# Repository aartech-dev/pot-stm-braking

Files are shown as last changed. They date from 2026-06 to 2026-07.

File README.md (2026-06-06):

# AART Slot Car Braking Module

## TODO

    - Verify the design  
    - Get AI to produce KiCad files - again and retrofit the pretty libs etc.

**AART — Adrian & Richard's Technologies**

An [open source](https://creativecommons.org/licenses/by-nc-sa/4.0/) standalone electronic braking controller for slot car racing, supporting brushed and brushless motors. Connects between the hand controller and the track via standard 4mm banana plugs. Compatible with any conventional resistor or transistor hand controller.

> *With thanks to Bob Budge for the original concept.*

---

## What it does

When a driver releases the trigger, a conventional hand controller shorts the track terminals. The motor becomes a generator and this module controls how that energy is absorbed — from a gentle soft brake through to a dead short, with optional positive anti-brake injection and brushless eCom keep-alive.

Three operating modes cover the main competition use cases:

| Mode | Toggle position | Use case |
|---|---|---|
| **A — Positive anti-brake** | A | Brushed motors (high-Kv, Group 12) where hard braking causes deslotting. Pot: CCW = soft brake → centre = dead short → CW = forward voltage injection (0–2V) |
| **B — Reduced braking** | B | Brushed motors needing fine brake adjustment. Full pot range: CCW = ~8Ω → CW = dead short |
| **C — Brushless keep-alive** | C | Brushless motors with eCom. Brake resistance same as mode B, plus a continuously-present low voltage keeps the eCom MCU powered at all times |

**Brake detection** is by voltage sense on the track positive (BLACK) terminal — no mechanical wiper strip contact required. Compatible with any hand controller.

**Brake ramp-in** (modes A and B): configurable exponential onset from 0 to 200ms, giving the "active coast" feel of advanced commercial controllers.

---

## Physical connections

Six 4mm banana sockets — three to the track, three to the hand controller:

| Colour | Signal | Notes |
|---|---|---|
| WHITE | +12–16V always-live rail | From track PSU (40–90A capable). Powers the module. |
| BLACK | Track positive | To car via right-hand braid. Monitored for brake detection. |
| RED | Common negative | Left-hand braid return. |

The module mirrors these three sockets on its output side for the hand controller to plug into.

---

## Repository layout

```
pot-stm-braking/
├── aart-brake-ocm3-fixed/      # Firmware (libopencm3, Docker toolchain)
│   ├── Dockerfile
│   ├── docker-compose.yml
│   ├── firmware/
│   │   ├── Core/
│   │   │   ├── Inc/brake_module.h   # Constants, pin map, types, API
│   │   │   └── Src/
│   │   │       ├── brake_module.c   # Control logic, ADC/DMA, PWM, flash
│   │   │       └── main.c           # SysTick ISR, fault handlers, main loop
│   │   ├── Makefile
│   │   └── stm32g041j6.ld           # Custom linker script (page 31 reserved)
│   └── scripts/
│       ├── build.sh
│       ├── flash.sh
│       └── debug.sh
├── aart-brake-kicad/               # KiCad schematic and BOM
│   ├── aart_brake.kicad_pro
│   ├── aart_brake.kicad_sch
│   └── aart_brake_bom.csv
├── scripts/                        # Document generator
│   └── gen_doc.js
├── AART_Braking_Module_Design_v8.docx   # Full design document
└── README.md
```

---

## Hardware

**MCU:** STM32G041K6U6 (QFN-32, Cortex-M0+, 32K flash, 8K RAM, 64MHz)

**Key pin assignments:**

| Pin | Signal | Function |
|-----|---|---|
| PA0 | WHITE sense | ADC — 16V rail ÷ 18k/4k7 divider → 3.31V max |
| PA1 | BLACK sense | ADC — track voltage ÷ 22k/4k7 divider → 2.82V max. Brake detection. |
| PA2 | Toggle bit 0 | GPIO pull-up — mode select |
| PA3 | Pot wiper | ADC — 10k centre-detent pot |
| PA4 | Toggle bit 1 | GPIO pull-up — mode select |
| PA5 | Capture button | ADC — 10k pull-up + 1k series. ~4095 unpressed, ~372 pressed |
| PA6 | TIM3_CH1 | Brake PWM → GD1 → Q1 (N-ch, **inverted polarity**) |
| PA7 | TIM3_CH2 | Keep-alive PWM → GD2 → Q2 (P-ch, normal polarity) |
| PB6 | Status LED | Blinks 3× on flash save |

**Power components (revised after thermal analysis):**

| Ref | Part | Notes |
|-----|---|---|
| Q1 | IRLB3034 N-ch D2PAK | Brake FET, 195A/40V, 1.4mΩ Rds(on) |
| Q2 | IRF9Z34N P-ch D2PAK | Keep-alive/anti-brake FET, 18A/55V |
| D1 | **P6KE18CA** (bidirectional) | TVS rail clamp — CA suffix required for both polarities |
| D2/D3 | **SS310** (3A/100V) | FET catch diodes — 100V rating required on 16V rail |
| D4 | **MBRS360 or SS54** | Mode C series protection — most stressed diode, sees repetitive ~46A pulses at 20kHz |
| F1 | 500mA–1A polyfuse | **WHITE rail MCU supply only** — never in the BLACK track path |
| U2 | AMS1117-3.3 SOT-223 | LDO, 12–16V → 3.3V |

> **D4 is essential in mode C.** Without it, Q2's body diode takes the full braking energy pulse every time Q1 fires. See design document section 3.5 for the full thermal analysis.

---

## Firmware

Built with [libopencm3](https://github.com/libopencm3/libopencm3) — no ST HAL, no CubeMX, no proprietary dependencies.

**ADC scan (4 channels, DMA circular):** WHITE rail → BLACK track → pot → capture button

**PWM:** TIM3 at 20kHz. CH1 uses **inverted polarity** (CCR=0 → pin HIGH → Q1 on → dead short). This means the 10kΩ pull-up on GD1's input holds the brake on when the MCU is unpowered — the safe failure mode.

**Brake ramp-in** uses an exponential geometric decay:
```
ccr += (target − ccr) × alpha / 256   (each 1ms tick)
```
`alpha` is derived from the saved ramp time: 0ms = immediate, 200ms = slowest. The shape gives fast initial brake onset (prevents running wide) with a gentler tail (avoids snap-stop).

**Flash storage (page 31, address 0x08007C00):**
```
[63:48] ramp_ms    (0–200ms)
[47:32] ka_ccr     (0–400, keep-alive CCR)
[31:0]  magic      (0xAA270001)
```

---

## Building

### Prerequisites

- Docker Desktop (Apple Silicon Mac — linux/arm64)
- Git

### Build the Docker image

```bash
cd aart-brake-ocm3-fixed
docker build --target toolchain -t aart-brake:toolchain .
```

First build: ~5 minutes (ARM GCC 13.3 download + libopencm3 G0 compile). Subsequent builds are cached and near-instant.

### Compile

```bash
# Debug build
docker compose run --rm brake build

# Release build
docker compose run --rm brake build release
```

Output lands in `./build/` on the host:

| File | Description |
|---|---|
| `aart_brake.elf` | Debug ELF with symbols (GDB) |
| `aart_brake.hex` | Intel HEX |
| `aart_brake.bin` | Raw binary |
| `aart_brake.map` | Linker map |

Typical size: ~5–6KB text, well within 32K flash.

### Flash (recommended: build in Docker, flash from host)

Docker Desktop on macOS does not reliably pass USB devices to containers.

```bash
# ST-Link
brew install stlink
st-flash write build/aart_brake.bin 0x08000000

# Or via OpenOCD
brew install openocd
openocd -f interface/stlink.cfg -f target/stm32g0x.cfg \
    -c "program build/aart_brake.elf verify reset exit"
```

### Debug (GDB via OpenOCD)

```bash
docker run --rm --privileged -it \
    -v "$(pwd)/build:/workspace/build" \
    -v "$(pwd)/firmware:/workspace/firmware" \
    -p 3333:3333 \
    aart-brake:toolchain \
    /workspace/scripts/debug.sh stlink
```

GDB connects automatically and breaks at `main()`.

---

## Capture procedure

### Keep-alive voltage (mode C — brushless)

1. Set toggle to **C**
2. Hold capture button — brake is suspended, pot dials Q2 output 0→2V
3. Rotate pot CW slowly until eCom powers up (LED or other indicator)
4. Continue slowly until motor just begins to twitch, then back off slightly
5. Release button — voltage saved to flash, LED blinks 3×
6. Power cycle to verify: eCom should power on immediately

### Brake ramp time (modes A and B)

1. Set toggle to **A** or **B**
2. Hold capture button — pot dials ramp time CCW=0ms → CW=200ms
3. Release button — ramp time saved to flash, LED blinks 3×

Starting points: wing cars 80–150ms, pan cars 0–30ms.

---

## libopencm3 G0-specific notes

The STM32G0 has several differences from F-series that affect libopencm3 usage:

- **DMAMUX** — G0 DMA uses a DMAMUX peripheral. ADC1→DMA1 CH1 requires writing `MMIO32(0x40020800) = 5` (not available via the library on all versions)
- **ADC scan** — `adc_enable_scan_mode()` does not exist on G0; scan is implicit when sequence length > 1
- **ADC symbols** — `ADC_CFGR1_RES_12_BIT` not `ADC_RESOLUTION_12BIT`; `ADC_SMPR_SMPx_039DOT5CYC` not `ADC_SMPR_SMP_39DOT5CYC`
- **Timer reset** — use `rcc_periph_reset_pulse(RST_TIM3)` not `timer_reset()`
- **Linker script** — libopencm3 dropped per-device `.ld` files; `stm32g041j6.ld` is provided in the repo with `MEMORY{}` + `INCLUDE cortex-m-generic.ld`
- **Flash writes** — G0 flash requires 64-bit aligned double-word writes

---

## BSCRA / ISRA legality

Anti-brake and keep-alive voltages are sourced directly from the WHITE (track PSU) rail. No stored energy — no capacitors, batteries, or supercapacitors. This satisfies the direct track power requirement in current BSCRA and ISRA controller regulations. Verify against specific class rules for your event.

---

## Design document

`AART_Braking_Module_Design_v8.docx` covers:

- Physical connections and signal chain
- Three-mode operation with FET truth tables
- Hardware component list with power/thermal analysis
- Pin assignments and voltage divider calculations
- Peripheral configuration (clock, TIM3, ADC, DMA, flash)
- Key design decisions with rationale
- libopencm3 build notes and G0-specific API differences
- Docker toolchain setup
- Pre-commissioning checklist and scope verification sequences
- On-track tuning guidance
- Industry terminology (positive anti-brake vs reduced braking)
- Brake ramp-in theory and setup recommendations
- Power and thermal analysis for all power-carrying components

---

## Toolchain

| Tool | Version |
|---|---|
| arm-none-eabi-gcc | 13.3.rel1 (ARM official, arm64 native) |
| OpenOCD | 0.12.0 (via Debian Bookworm apt) |
| libopencm3 | master (cloned and built in Docker image) |
| Base OS | Debian Bookworm slim |

---

## Acknowledgements

- Bob Budge — original concept
- Arseny Vakrushev — ESCape32 firmware (related AART work)
- Keith Gibson — brake module contributions
- libopencm3 contributors

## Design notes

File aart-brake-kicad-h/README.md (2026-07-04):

# AART Brake Module — KiCad Schematic (hierarchical, Revision 11)

Firmware Rev 11 design. Open `aart_brake.kicad_pro` in **KiCad 7.0+**.
The schematic is hierarchical: the root sheet (`aart_brake.kicad_sch`)
contains seven sub-sheet symbols. These are annotation-style sheets
(net labels + text callouts; no placed library symbols), so they open
without missing-symbol warnings and document the design for layout.

## Sheets
| # | File | Contents |
|---|---|---|
| root | `aart_brake.kicad_sch` | Top level, component list, design notes |
| 1 | `power_supply.kicad_sch` | F1, D1 TVS, U2 +3V3 LDO, **U4 +5V analog LDO** (powers INA210/LM311 ideal diode; gate-drive charge pump from WHITE) |
| 2 | `mcu_inputs.kicad_sch` | U1 STM32G051, **DAC1 PA4 brake, DAC2 PA5 anti-brake**, pot, toggle PB0/PB1, sense |
| 3 | `debug_headers.kicad_sch` | SWD, UART, BOOT0, NRST |
| 4 | `brake_fet.kicad_sch` | **Q2 TW100N03CC** low-Rds logic-level, **GD2 op-amp buffer**, linear (no PWM) |
| 5 | `keepalive_fet.kicad_sch` | **Anti-brake constant-current source: GD1 + Q1 TIP147 + Rsense 0.1ohm, DAC2-set 3A** |
| 6 | `track_connectors.kicad_sch` | J1-J6 banana; BLACK split by the reverse switch |
| 7 | `reverse_switch.kicad_sch` | **Q5/Q6 N-ch pair + U5 INA210 + U6 LM311 ideal diode (~2us, ~0.16A trip)** |

## Latest design changes (Revision 11)
- **Reverse-block driver is now an INA210 + LM311 ideal diode**, replacing the TPS1212-Q1.
  An INA210 current-sense amp (gain 200, +5V) across Rsns_sw (~1mohm) feeds an LM311 comparator
  (~50mV hysteresis, ~0.16A trip) that turns the Q5/Q6 pair off on reverse current in ~2us (sim) -
  ~13x lower glitch energy than the TPS1212, so a smaller eCom brownout when the brake contact closes.
  This drops the TPS1212 I2t/SCP/IMON automotive protection (open item: the brake event is brief and
  the rest of the design is unprotected, but the pass FETs lose their own fault protection). OPEN ITEMS:
  a high-side gate driver / charge pump (from WHITE) must lift the gates above the 0-16V BLACK common
  source; the ~2us speed and the 26V INA210 CM ceiling need bench validation.
- **Anti-brake is now a constant-current source** (3A), not a voltage follower. GD1 op-amp +
  Q1 TIP147 PNP Darlington + 0.1ohm sense; demand is DC from DAC2 (R_KA1/R_KA2 divider + GD3 LM7321 translator).
  Bounds the current at stall (a near-short on the start line) and matches real controllers.
  Anti-brake net is KA_DAC_DEMAND; PA5 = DAC2 (DAC_CH2) direct DC demand.

## What changed across earlier schematic revisions (now unified as Revision 11)
This schematic was two design generations behind. Updated to match the
current design document (v29) and firmware Rev 11:

- **DAC, not PWM.** PA4/PA5 dual DAC drive op-amp buffers in linear mode.
  TIM3 PWM gate drive retired. (PB4 now drives the TM1637 digital display; the PB4 voltmeter PWM is retired.)
- **Op-amp buffers, not UCC27524** for both gate channels.
- **Anti-brake = constant-current source** (Q1 TIP147 + GD1 HV op-amp + Rsense
  0.1ohm), superseding the earlier TIP122 voltage follower. DAC2 sets the current
  demand via R_KA1/R_KA2 + GD3 LM7321: code 0 = off, full = 3A (DAC_KA_OFF is now 0).
  Retired: IRF9Z34N, ZD1/R_Z1/C_Z1, LM321 floating supply; TIP122 follower.
- **Brake FET → Q2 TW100N03CC** (low-Rds logic-level, full-on for brushless;
  IRFP250N = brushed-only alt). Q1 (TIP147) runs linear ~10-15W and **requires a heatsink**.
- **Reverse-block pass element (sheet 7):** two N-channel (Q5/Q6, common-source)
  + U5 INA210 + U6 LM311 ideal-diode controller (ICs on +5V), with Rsns_sw (~1mohm)
  sense, ~0.16A reverse trip, ~50mV hysteresis, ~2us. No I2t/SCP/IMON; gate-drive charge
  pump from WHITE (open item). Supersedes the TPS1212-Q1. ~87mV at 40A.
- **Toggle PB0/PB1**, capture button removed, **PB3 free** (the ideal diode
  has no enable input; the TPS1212 EN is gone).
- **+5V analog rail (U4)** for the GD2 brake gate buffer (GD1 runs on WHITE).

## Net names
| Net | Description |
|---|---|
| `+12V_RAIL` | WHITE, always-live 12-16V from track PSU |
| `+3V3` | MCU rail (U2) |
| `+5V` | Analog rail (U4): GD2 brake gate buffer |
| `GND` | Common ground (RED rail / 0V) |
| `CTRL_BLACK_IN` | Controller BLACK in (J4) → reverse switch input |
| `TRACK_POS` | Track BLACK (J3); switch output; motor +; injection node |
| `DAC1_Q2_BRAKE` / `KA_DAC_DEMAND` | DAC1 brake; DAC2 anti-brake demand |
| `PB3` | Free GPIO (was reverse-switch enable; ideal diode has no enable) |

## Note on the .kicad_pro
Child sheets are referenced by the sheet symbols in the root `.kicad_sch`;
KiCad assigns page numbers/UUIDs on first open. The hierarchy will populate
automatically. These sheets are documentation-grade (labels + callouts);
place real symbols/footprints in KiCad for board layout.

Revision 11 — 19 June 2026 — AART (Adrian & Richard's Technologies)

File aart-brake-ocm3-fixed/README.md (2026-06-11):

# AART Brake Module — Docker Toolchain (libopencm3)

STM32G051K6U6 firmware built with **libopencm3** — no ST HAL,
no CubeMX, no proprietary dependencies. Everything in the repo.

---

## Why libopencm3?

- Fully open source (LGPL) — the library lives in the repo as a submodule
- No CubeMX, no ST account, no generated code blobs
- Direct register-level control with thin, readable wrappers
- Smaller binaries than HAL
- One important difference on G0: the DMA controller uses a **DMAMUX**
  which must be configured explicitly (see `dma_setup()` in brake_module.c)

---

## Project layout

```
aart-brake-ocm3/
├── Dockerfile              # base → toolchain → cubeprog (optional)
├── docker-compose.yml
├── README.md
├── .dockerignore
├── .gitignore
├── .gitmodules             # libopencm3 as submodule
├── firmware/
│   ├── Core/
│   │   ├── Inc/
│   │   │   └── brake_module.h
│   │   └── Src/
│   │       ├── main.c
│   │       └── brake_module.c
│   └── Makefile
├── scripts/
│   ├── entrypoint.sh
│   ├── build.sh
│   ├── flash.sh
│   └── debug.sh
└── build/                  # created at build time, gitignored
```

---

## Prerequisites

- Docker Desktop for Mac (Apple Silicon)
- Git (for submodule init)
- ST-Link V2/V3 or J-Link probe

---

## First-time setup

### 1. Initialise the libopencm3 submodule

After cloning the repo:

```bash
git submodule update --init --recursive
```

This is only needed on the host if you want to browse the source.
The Docker image clones libopencm3 independently at build time
and pre-builds the G0 library — so the submodule is optional
for Docker users but useful for IDE navigation.

The `.gitmodules` entry looks like this:
```ini
[submodule "libopencm3"]
    path = libopencm3
    url = https://github.com/libopencm3/libopencm3.git
    branch = master
```

### 2. Build the Docker image

```bash
docker build --target toolchain -t aart-brake:toolchain .
```

First build: ~5 minutes (ARM GCC download + libopencm3 compile; OpenOCD from apt is fast).
Subsequent builds: seconds (all layers cached).

---

## Compile the firmware

```bash
# Debug build (default)
docker compose run --rm brake build

# Release build (optimised, no debug symbols)
docker compose run --rm brake build release
```

Or directly without compose:
```bash
docker run --rm \
    -v "$(pwd)/firmware:/workspace/firmware" \
    -v "$(pwd)/build:/workspace/build" \
    aart-brake:toolchain \
    /workspace/scripts/build.sh
```

Output in `./build/`:
| File | Description |
|---|---|
| `aart_brake.elf` | Debug ELF with symbols (for GDB) |
| `aart_brake.hex` | Intel HEX (for CubeProgrammer) |
| `aart_brake.bin` | Raw binary |
| `aart_brake.map` | Linker map |

Expected size on STM32G051K6U6 (32K flash, 18K RAM, DAC):
- Text: ~4–6 KB
- BSS: ~100 bytes
- Very comfortable margins.

---

## Flash the firmware

**Recommended on macOS: build in Docker, flash from host.**

Docker Desktop on macOS does not reliably pass USB devices
through to containers. The simplest workflow is:

```bash
# 1. Build inside Docker
docker compose run --rm brake build

# 2. Flash from host using ST-Link tools (install via Homebrew)
brew install stlink
st-flash write build/aart_brake.bin 0x08000000

# OR using openocd on the host
brew install openocd
openocd \
    -f interface/stlink.cfg \
    -f target/stm32g0x.cfg \
    -c "program build/aart_brake.elf verify reset exit"
```

**If you want to flash from inside the container:**
```bash
docker run --rm --privileged \
    -v "$(pwd)/build:/workspace/build" \
    aart-brake:toolchain \
    /workspace/scripts/flash.sh stlink
```
Note: `--privileged` is required for USB access on macOS.

---

## Debug (GDB)

```bash
# Start OpenOCD + GDB inside the container
docker run --rm --privileged -it \
    -v "$(pwd)/build:/workspace/build" \
    -v "$(pwd)/firmware:/workspace/firmware" \
    -p 3333:3333 \
    aart-brake:toolchain \
    /workspace/scripts/debug.sh stlink
```

GDB breaks at `main()` automatically. Useful commands:

```gdb
(gdb) p s_state              # print full BrakeState_t struct
(gdb) p brake_get_mode()     # current mode
(gdb) info locals            # local variables in current frame
(gdb) x/2h &s_adc_buf        # raw ADC DMA buffer (hex halfword)
(gdb) monitor reset halt     # reset MCU and halt
(gdb) continue               # run
(gdb) quit
```

---

## libopencm3 — G0-specific notes

### DMAMUX
The STM32G0 family routes DMA requests through a DMAMUX
peripheral, unlike F0/F1 where the mapping is fixed.
You must configure `DMAMUX1_CxCR` for each DMA channel.

In `brake_module.c`:
```c
// Route ADC1 (request ID 5) to DMA1 Channel 1
dmamux_set_dma_channel_request(DMAMUX1, 0, ADC_DMAMUX_REQ);
```
If you add more DMA channels, set DMAMUX accordingly.

### ADC calibration
On the G0 ADC, `adc_calibrate()` must be called **before**
`adc_power_on()`. libopencm3 handles this correctly if called
in the right order — see `adc_setup()` in brake_module.c.

### Linker script
libopencm3 ships `stm32g051k6.ld` with the correct
flash (32K) and RAM (8K) sizes for this exact part.
No need to write your own.

### ISR names
libopencm3 uses lowercase ISR names with weak defaults:
- `sys_tick_handler` — SysTick (1ms tick)
- `hard_fault_handler` — HardFault (force brake)
- `nmi_handler` — NMI (force brake)
- `dma1_channel1_isr` — DMA complete (ADC results ready)

Override them in your C files — no startup file editing needed.

---

## Optional: STM32CubeProgrammer stage

Download `SetupSTM32CubeProgrammer.linux` from ST (free myST account),
place in `./installers/`, then:

```bash
docker build --target cubeprog -t aart-brake:full .
```

Flash with CubeProgrammer:
```bash
docker run --rm --privileged \
    -v "$(pwd)/build:/workspace/build" \
    aart-brake:full \
    STM32_Programmer_CLI -c port=SWD -w /workspace/build/aart_brake.elf -v -rst
```

---

## Toolchain versions

| Tool | Version |
|---|---|
| arm-none-eabi-gcc | 13.3.rel1 |
| OpenOCD | 0.12.0 (via apt, Debian Bookworm) |
| libopencm3 | master (pinned at image build) |
| Base OS | Debian Bookworm slim |

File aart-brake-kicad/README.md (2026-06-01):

# AART Brake Module — KiCad Schematic

## Files

| File | Description |
|---|---|
| `aart_brake.kicad_pro` | KiCad project file — open this in KiCad |
| `aart_brake.kicad_sch` | Schematic — single sheet, A2 paper |
| `aart_brake_bom.csv` | Bill of materials with footprints and notes |

## Opening

Open `aart_brake.kicad_pro` in **KiCad 7.0 or later**. The schematic
uses only inline symbol definitions (no external library dependencies),
so it should open without any missing symbol warnings.

## Schematic layout

The sheet is arranged left-to-right by signal flow:

```
[Connectors/Inputs] → [MCU U1] → [Gate Drivers GD1/GD2] → [FETs Q1/Q2] → [Track Connectors]
[Power rail J2/F1/D1/U2] runs across the top
[Status LED] sits below the MCU
```

## Key design decisions (see also design document)

**Q1 (brake FET, N-ch low-side):**
TIM3_CH1 uses INVERTED output polarity. CCR=0 → pin HIGH → Q1 fully on → dead short.
The 10kΩ pull-up R2 is on the GD1 *input* (not Q1's gate). When the MCU is unpowered,
R2 holds GD1 input HIGH → Q1 stays on → motor remains shorted = safe default.

**Q2 (keep-alive FET, P-ch high-side):**
IRF9Z34N with gate driven by GD2 (UCC27524). P-channel: gate LOW = FET on.
TIM3_CH2 uses normal polarity: CCR=0 → pin LOW → Q2 off.

**D4 (mode C protection):**
SS34 Schottky in series with Q2 drain output, oriented so current flows
Q2 → D4 → track+. When Q1 hard-brakes (dead short), D4 blocks the reverse
current spike from the track back through Q2's body diode.
D4 is ESSENTIAL for mode C. It can be omitted on mode A/B-only boards.

**Gate driver note:**
The UCC27524 is a dual low-side gate driver. Both outputs (OUTA, OUTB) are
wired in parallel for each FET to double the gate drive current capability.
For Q2 (P-channel), the driver output drives the gate low to turn the FET on.
The gate drive supply for GD1/GD2 is 3.3V (from U2). Verify that 3.3V is
sufficient to fully enhance the chosen FETs (Vgs(th) must be < 3.3V).
Both IRLB3034 and IRF9Z34N are logic-level parts and work correctly at 3.3V.

## Net names

| Net | Description |
|---|---|
| `+12V_RAIL` | Always-live 12.4V from track PSU |
| `+3V3` | 3.3V from LDO U2 |
| `GND` | Common ground |
| `TRACK_POS` | Track positive output (to car) |
| `TRACK_NEG` | Track negative / GND |
| `CTRL_IN` | Hand controller output (0–12.4V) |

## Schematic version

Rev 1.0 — May 2026 — AART (Adrian & Richard's Technologies)

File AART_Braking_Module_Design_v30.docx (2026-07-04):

AART Slot Car Braking Module

Design Document

Target MCU: STM32G051K6U6 (QFN-32) | Firmware: Rev 11 | libopencm3

Revision 11 | 19 June 2026 | AART — Adrian & Richard’s Technologies

PRIVATE & CONFIDENTIAL

With gratitude to Jeff Goldberg for his manifold contributions to this work.

# 1. Overview

This document describes the hardware design and firmware architecture for the AART slot car braking module. The module connects in-line between a conventional hand controller and the track, providing variable resistance braking, positive anti-brake for brushed motors, and a keep-alive voltage floor for brushless motors. All three functions are controlled by a three-position toggle switch and a single linear potentiometer, with fine tuning via UART commands.

## 1.1 Purpose

The AART brake module provides three capabilities, controlled by a three-position toggle switch, a linear potentiometer, and UART commands:

- Braking — for brushed and brushless motors. Q2 shunts a variable resistance across the motor terminals. The pot governs brake force from a settable minimum (selectable 25/15/5/4/3/2/1Ω via SET BRAKE_OHMS, full CCW) to dead short (full CW). Fine electronic control replaces the fixed resistor of a conventional brake.
- Anti-brake — for brushed motors (Mode B). While braking, Q1 injects a small forward current from the WHITE rail that opposes the brake, countering the back-EMF that makes the car snap on corner entry. The pot simultaneously governs both brake resistance and anti-brake level through a lookup table: lighter braking gives more anti-brake, harder braking less.
- Keep-alive floor — for brushless motors (Mode A with floor set). The eCom is powered from the braid. Conventional braking collapses the braid voltage to near zero, resetting the eCom. Q1 clamps the braid above a settable floor, preventing brownout. The floor is set by rotating the pot in Mode C then toggling to Mode A.

Parameters requiring fine or infrequent adjustment — ramp-in time, trail brake release, brake entry/exit thresholds, and Latvian brake — are set via UART and saved to flash.

The module is fully compatible with any conventional hand controller and requires no modification to the controller or the car.

## 1.2 System position

The module connects via 4mm banana plugs to the three standard track sockets and exports matching sockets for the hand controller to plug into. It is fully transparent during normal running and takes over braking when the controller shorts the track.

Banana colour | Signal | Description
WHITE | +12–16V always-live rail | From track PSU. Can deliver 40–90A. Powers the module and Q1 injection.
BLACK | Track positive (+ve to car) | Controlled by hand controller. Monitored by module to detect brake condition.
RED | Common negative | Left braid return. Module and track ground reference.

The module presents identical WHITE/BLACK/RED sockets on its output side for the hand controller to plug into. During normal running, BLACK passes through unmodified. When the hand controller shorts BLACK→RED (brake condition), the module detects this by voltage sense on the BLACK terminal and applies its own controlled braking.

The WHITE rail is always live at 12–16VDC regardless of throttle position. The hand controller varies how much of this rail reaches the BLACK output. The module draws its MCU supply from WHITE via the LDO. WHITE is also the source for Q1 (anti-brake injection and keep-alive floor).

## 1.3 Circuit topology

The diagram below shows the principal signal paths through the module. All three rails (WHITE, BLACK, RED) run left to right. The hand controller connects on the left; the track and motor are on the right.

[Figure 1: Circuit topology diagram — see AART_Brake_Topology.svg delivered alongside this document]

Key points from the diagram:

- The reverse-blocking switch (two N-channel + INA210/LM311 ideal diode, section 7A.2) sits in the BLACK controller input path — not the WHITE rail. During normal running it is fully transparent (near-zero voltage drop). During brake takeover it opens, isolating the controller’s short from the track.

Note: The reverse-blocking element is a two N-channel common-source bidirectional switch controlled as an ideal diode by an INA210 current-sense amp and an LM311 comparator (both on +5V), not an anode-powered ideal-diode IC — see section 7A.2. The LM311 turns the pair off on reverse current in ~2µs (sim), with a ~0.16A trip threshold and ~50mV hysteresis. This drops the automotive I²t / 5µs short-circuit / IMON protection of the earlier TPS1212-Q1 (open item). Insertion drop ~87mV at 40A including the sense resistor.

- Q1 (TIP147 PNP Darlington) is the pass device of the anti-brake / keep-alive constant-current source: the WHITE-rail op-amp GD1 regulates the current through Q1 and Rsense (0.1Ω) to I = Vdemand/Rsense, up to ~3A. In Mode A it holds the saved keep-alive floor whenever V_BLACK drops below it; in Mode B it injects anti-brake current after brake exit; in Mode C it previews the floor live while the driver tunes it. The demand is a clean DC voltage from DAC2 (DAC_OUT2 on PA5), divided down to set the target (section 7A.7).
- Q2 (low-Rds logic-level N-channel, low-side) connects BLACK_to_track to RED/GND. For brushed motors it is held in its linear region at a selectable brake resistance (25/15/5/4/3/2/1Ω via SET BRAKE_OHMS, down to a near dead short); for brushless motors it is driven full-on, shorting the on-car ESC bus so the motor brakes through the Remora’s body-diode rectifier. Its gate is driven by GD2, an op-amp buffer with gain ~1.5, from DAC1 (sections 7A.10–7A.12).
- The track-facing devices never hard-switch. For the brushed brake the DAC sets Q2’s gate to a DC voltage, so it presents a continuously variable drain-source resistance — no 20kHz switching, no radiated EMI, no interference with brushless eCom electronics; for the brushless brake Q2 is simply held fully on. The anti-brake stage is a constant-current source whose demand is a clean DC voltage from DAC2, so nothing on the track node switches at all.
- The MCU senses WHITE dV/dt (for Latvian brake detection), V_BLACK_to_track (for brake entry/exit hysteresis), and the pot and mode switches. It generates the DAC1 brake voltage and the 50kHz anti-brake PWM demand accordingly.
- The R10/R11 voltage divider sensing BLACK_to_track is on the motor side of the reverse-blocking pass switch — this is essential so the MCU can detect the voltage collapse that occurs when that switch opens and the module takes over braking.

## 1.4 Circuit-by-circuit description (theory of operation)

A guided tour of each functional circuit in the module, in signal-flow order — what it does, how it works, and its key parts. The detailed analysis of each lives in the referenced sections; the topology diagram (§1.3) shows how they connect.

Power input and rails — Three rails run through the module: WHITE (the 12–16 V track PSU, always live), BLACK (the controller-to-track drive/signal, swinging 0→rail) and RED (0 V/GND). An LDO derives 3.3 V for the MCU; a second LDO (U4) derives the +5 V GD2 rail. A 100 µF hold-up capacitor keeps the MCU and brake stage alive through a PSU power-off, so braking still works when track power is cut (§7A.6).

Reverse-blocking pass switch — Q5/Q6, a back-to-back N-channel pair in the BLACK controller-input path, controlled as an ideal diode by an INA210 + LM311 (both on +5V). It passes forward controller current at a low insertion drop and blocks reverse current in ~2µs; the LM311 output also drives the MCU brake-detect on PA6. It sits in the BLACK path, not the WHITE rail (§7A.2).

MCU and power supervisor — An STM32G051K6 (QFN-32) at 64 MHz runs the control loop. It senses WHITE dV/dt (Latvian-brake trigger), V_BLACK_to_track (brake entry/exit hysteresis), the control pot and the mode toggles; and it drives DAC1 (brake), DAC2 (anti-brake demand), the TM1637 display (PB4/PB8), the status LED, USART1 (telemetry/flashing) and SWD. Its BOR/POR supervisor plus the hold-up cap let braking survive a brownout (§7A.5, §7A.6).

Brake detection — The R10/R11 divider senses V_BLACK_to_track on the motor side of the pass switch, and firmware applies hysteresis to decide brake entry and exit — when the controller is released and the drive collapses, the module enters braking (§2.1).

Brake stage (Q2 + GD2) — Q2 is a low-Rds logic-level N-channel FET, low-side from BLACK_to_track to RED. Its gate is driven by GD2, an LM7321 rail-to-rail-output op-amp on +5 V with a gain of ~1.5 that lifts the 3.3 V DAC to a ~5 V gate. For brushless motors Q2 is driven full-on — shorting the on-car ESC bus, which brakes through the Remora’s body-diode rectifier; for brushed motors it is held in its linear region at a selectable resistance (the 1–25 Ω tables). A catch diode (D2) and heatsink complete the stage (§7A.10–7A.12, §11.2).

Anti-brake / keep-alive current source (GD1 + Q1) — GD1, an LM7321 rail-to-rail-input op-amp on the WHITE rail, closes a constant-current loop around Q1 (a TIP147 PNP Darlington pass device) and Rsense (0.1 Ω). A clean DC demand from DAC2 (DAC_OUT2 on PA5) sets the target, and GD1 regulates I = Vdemand/Rsense up to ~3 A, injecting a controlled forward current into BLACK_to_track — positive anti-brake in Mode B, and a keep-alive floor for brushless motors that keeps the ESC responsive (held in Mode A, tuned live in Mode C). D4 (MBRS360) blocks reverse (§7A.7).

Digital display — A TM1637 4-digit LED module on J14, driven directly by the MCU over a 2-wire serial link (CLK = PB4, DIO = PB8), shows the WHITE rail voltage in Modes A/B and the live keep-alive floor in Mode C. The MCU sends exact digits, so there is no analog proxy, RC filter, or scaling.

USB-C / UART bridge — A CH340N USB-to-UART bridge on J11 carries telemetry and runtime SET commands; field firmware updates run through the STM32 ROM UART bootloader using the BOOT0/NRST buttons (§7A.9, §14).

# 2. Operating Modes

The module has three operating modes selected by a 3-position toggle switch. Within each mode the brake is triggered by voltage sense on the BLACK terminal rather than a mechanical wiper strip contact, making the module compatible with any hand controller.

## 2.1 Brake detection — current direction (I_DIR) with V_BLACK hysteresis

Two signals drive brake detection. The primary is the reverse-detect flag on PA6 (the LM311 ideal-diode output): reverse current through the pass switch means the controller is braking, latched and held across brief reverse-detect dropouts. The BLACK terminal voltage (PA1) is also monitored, with a hysteresis band, to catch coast/lift-off and to exit when the controller drives forward again:

- I_DIR asserted (reverse current) → enter brake state and hold — controller is braking
- V_BLACK < 500mV → enter brake state (controller has shorted BLACK→RED)
- V_BLACK > 1500mV → exit brake state (controller delivering power)
- 500mV ≤ V_BLACK ≤ 1500mV → hold current state

This approach works with any hand controller regardless of whether it has an accessible wiper strip contact, and correctly handles partial braking (controllers that do not short fully to zero).

## 2.2 Mode A — Brake only (brushed and brushless)

V_BLACK | Pot position | Q1 (KA floor) | Q2 (brake) | Behaviour
> 1500mV | Any | OFF (KA floor injects only when V_BLACK drops below it) | OFF | Pass-through — module transparent. Q1 holds KA floor if configured.
< 500mV | Full CCW | OFF (during braking) | Configurable soft min (SET BRAKE_OHMS) | Softest brake at the selected resistance (25/15/5/4/3/2/1Ω).
< 500mV | CCW → CW | OFF (during braking) | Rising toward DAC_BRAKE_HARD | Brake firms progressively as pot turns CW.
< 500mV | Full CW | OFF (during braking) | DAC_BRAKE_HARD | Dead short — maximum braking.
< 500mV → released | Any | saved_ka_dac applied when V_BLACK < floor | OFF | Q1 maintains keep-alive floor (brushless). Default DAC_KA_OFF = pure braking.

## 2.3 Mode B — Brake and anti-brake (brushed motors)

State (detection) | Pot | Q1 (anti-brake) | Q2 (brake) | Net behaviour
Driving forward (I_DIR clear, V_BLACK high) | Any | OFF | OFF | Pass-through. No anti-brake injected while the driver is on throttle.
Braking (I_DIR reverse current, or V_BLACK collapse) | Full CCW | ka_dac_table[idx] | brake_tables[sel][idx] (soft) | Q1 and Q2 act together: anti-brake trims the brake most → softest net brake.
Braking | CCW → CW | ka_dac_table[idx] | brake_tables[sel][idx] (rising) | Net brake firms progressively as the pot index climbs.
Braking | Full CW | ka_dac_table[idx] | brake_tables[sel][idx] (dead short) | Q2 dominates → hardest net brake.

## 2.4 Mode C — Keep-alive tuning (brushless)

Mode C is a setup mode for brushless motors only. The pot dials the keep-alive floor voltage live (ka_dac_table[pot_idx]) which is applied to Q1 so the driver can verify the eCom powers up correctly. When the toggle leaves Mode C, the current pot value is saved as saved_ka_dac after a 500ms debounce. This saved value is then used by Mode A as the Q1 KA floor. Return to Mode A or B for racing.

V_BLACK | Pot position | Q1 (KA preview) | Q2 (brake) | Behaviour
Mode C active, V_BLACK high | Any | OFF | OFF (suppressed) | Q1 previewing floor, pot CCW = 0V floor
Mode C active, V_BLACK low | Any | OFF | Linear per pot (brake) | Braking + KA floor preview simultaneously
V_BLACK > 1500mV | Any | ka_dac_table[pot_idx] live | OFF | Q1 live, eCom can verify floor
V_BLACK < 500mV | Any | OFF (Q1 off during braking) | Linear per pot | Braking, pot = configurable soft → DAC_BRAKE_HARD
Toggle away from C | Any | OFF | Normal | 500ms debounce then save + LED 3×
Back in Mode A | Any | saved_ka_dac applied as floor | Linear per pot | Racing with KA floor active

During a hard brake (Q2 dead short), V_BLACK collapses toward 0V. Q1 is commanded off during braking in Mode C (per the table above), so it is not maintaining the floor here; the low impedance of Q2’s dead short would dominate in any case. D4 is essential in mode C — it blocks reverse current through Q1 when Q2 holds the track near 0V, protecting Q1’s body diode from the repetitive peak current.

# 3. Hardware Design

## 3.1 Component list

Ref | Component | Value / Part | Notes
U1 | MCU | STM32G051K6U6 | QFN-32, 3.3V, 64MHz
U2 | LDO regulator | AMS1117-3.3 (or MCP1700 — see 7A.6) | WHITE rail → 3.3V, SOT-223
GD1 (HV op-amp powered from the WHITE rail) is the current-source loop driving Q1 TIP147; Rsense 0.1ohm; D4 MBRS360 reverse block | Anti-brake current source | LM7321 RRIO HV op-amp (SOT-23); alt OPA192 | Keep-alive / anti-brake FET channel (Q1), SOT-23-5
Rsense | Current sense | 0.1ohm (1-2W) | 0.3V at 3A -> op-amp sets I=Vdemand/Rsense
GD3 | Demand translator | LM7321 RRIO HV op-amp (SOT-23) | WHITE-referenced unity difference translator: AB_DEMAND = WHITE − 0.30V (R_t1–R_t4 = 10k 0.1% matched; combinable with GD1 as one LM7322 dual)
R_KA1/2 | Demand divider | 6.8k / 1.2k | Ground-referenced demand divider → 0.30V into GD3
GD2 | Brake gate buffer | LM7321 RRO op-amp, gain ~1.5 (SOT-23); alt TLV9061 | Brake FET channel (Q2), SOT-23-5
Q1 | Anti-brake / keep-alive FET | TIP147 PNP Darlington | Anti-brake current-source pass, TO-220 + heatsink (or N-MOSFET alt)
Q2 | Brake FET | TW100N03CC ~3mΩ logic-level N-ch | 30V, ~3mΩ, D2PAK SMD
Q5, Q6 | Reverse-block N-ch pair | STL059N4S8AG (or SiJK140E) | Common-source bidirectional switch, BLACK path. 40V, ~0.59mΩ each.
U5 | Smart high-side switch controller | INA210 + LM311 | INA210 (gain 200, +5V) across Rsns_sw; LM311 (~50mV hysteresis) trips on reverse (~0.16A, ~2µs) → gate driver + PA6 brake-detect. No I²t/SCP/IMON. Gate-drive charge pump from WHITE (open item). SC70-6 / SOT23-5.
Rsns_sw | Sense resistor (Rsns_sw) | ~0.5-0.75mohm | Ideal-diode shunt; INA210 senses across it. ~40mV at 40A (~1mΩ). Sets the reverse threshold.
U7 | Glue logic | 1 transistor/gate | LM311 reverse-detect → gate driver off on reverse; output also feeds PA6 brake-detect.
R_THR1/R_THR2, R_HYS, R_CMP | LM311 threshold + hysteresis | caps + resistors | Set the reverse trip (~0.16A) via the R_THR divider and ~50mV via R_HYS; R_CMP pulls the LM311 output up to +3V3.
D1 | TVS diode | P6KE18CA (bidirectional) | Rail transient clamp, 18V, SMB. CA suffix essential — bidirectional variant clamps both polarity transients from inductive switching.
D2 | Schottky | SS310 | Q2 catch diode, 3A/100V SMB. 100V reverse voltage gives margin over SS34’s 40V on a 16V rail with inductive spikes.
D3 | Schottky | SS310 | Q1 catch diode, 3A/100V SMB. Same upgrade as D2.
D4 | Schottky | MBRS360 | Mode C series output diode — ESSENTIAL
D5 | LED red | 0805 | Status indicator PB6
F1 | Polyfuse | 500mA–1A, 1812 | WHITE rail supply protection for MCU/LDO only. Must NOT be in the BLACK (track) path — a polyfuse cannot handle 40A motor startup and will trip from thermal lag. The BLACK path carries full motor current; PSU overcurrent protection covers that rail.
R1 | 10kΩ | 0402 | NRST pull-up
R2 | 10kΩ | 0402 | GD2 input pull-up (safe default brake)
R3 | 10Ω | 0402 | Q2 gate resistor
R_BASE | 1kΩ | 0402 | Q1 base resistor (TIP147)
R5 | 10kΩ | 0402 | Pot top-end to 3.3V
R6 | 10kΩ | 0402 | PB3 reserved (no component fitted)
R7 | 1kΩ | 0402 | PB3 reserved — 1kΩ footprint, DNF
R8 | 18kΩ | 0402 | WHITE sense top divider (PA0)
R9 | 4k7Ω | 0402 | WHITE sense bottom divider (PA0)
R10 | 22kΩ | 0402 | BLACK sense top divider (PA1)
PA6 | I_DIR (brake detect) | GPIO input | LM311 reverse-detect flag (ideal diode); current-direction brake detection. CONFIRM level ≤3.3V (pull-up to +3V3).
R11 | 4k7Ω | 0402 | BLACK sense bottom divider (PA1)
R12 | 330Ω | 0402 | Status LED current limit
C1–C4 | Decoupling | 0805/0402 | 100nF + 10μF per LDO rail
C5–C7 | Decoupling | 0402 | 100nF VDD, 100nF VDDA, 4.7μF VDDA
J1–J3 | 4mm banana sockets | Track side | WHITE / BLACK / RED to track
J4–J6 | 4mm banana sockets | Controller side | WHITE / BLACK / RED from hand controller
J7 | 3-pin 2.54mm | Pot connector | 3.3V / wiper / GND
J8 | 3-pin 2.54mm | Mode toggle | Bit0 / Bit1 / GND
J9 | 2-pin 2.54mm | (reserved, was capture button) | Momentary pushbutton

## 3.2 Pin assignments — STM32G051K6U6 QFN-32

Pin | Signal | Type | Function
PA0 | WHITE sense | ADC_IN0 analog | WHITE rail ÷ R8/R9 divider. V_PA0 = V_WHITE × 0.2386. Safe to 16V.
PA1 | BLACK sense | ADC_IN1 analog | BLACK_to_track ÷ R10/R11 divider. Track side of the pass switch.
PA3 | Pot wiper | ADC_IN3 analog | 10k linear pot, 0–3.3V. No centre detent.
PA4 | Q2 brake gate | DAC_CH1 | 0–3.3V → GD2 op-amp → Q2. DAC_BRAKE_OFF…DAC_BRAKE_HARD.
PA5 | Q1 KA demand (DAC2) | DAC_OUT2 (analog) | DAC2 (DAC_OUT2 on PA5) → ground-referenced divider (6.8k/1.2k → 0.30V) → GD3 difference translator → GD1 current-source op-amp → Q1 TIP147. Sets anti-brake current (0=off … 3A). (DAC2 supplies clean DC; no PWM/RC filter.)
PA9 | USART1_TX | AF1 | UART TX to J11 / CH340N. 115200 8N1.
PA10 | USART1_RX | AF1 | UART RX from J11 / CH340N.
PB0 | Toggle bit 0 | GPIO input, pull-up | Active LOW. Decoded with PB1: see toggle table.
PB1 | Toggle bit 1 | GPIO input, pull-up | Active LOW. Decoded with PB0: see toggle table.
PB3 | (reserved) | GPIO | Previously capture button. Unused in Rev 11.
PB4 | TM1637 CLK | GPIO OD out | Display clock → J14 (TM1637)
PB6 | Status LED | GPIO output | Blinks 3× on keep-alive save to flash.
PB8 | TM1637 DIO | — | Display data → J14 (TM1637). PB8 freed by the BOOT0 = PA14 correction.

## 3.3 Voltage dividers

Both sense inputs use the same bottom resistor (4k7Ω) for component commonality. The top resistor differs to accommodate the different maximum voltages:

Signal | R_top | R_bot | Ratio | V_pin at 16V rail | Safe?
WHITE (PA0) | 15kΩ | 4k7Ω | 0.2386 | 3.82V — marginally over | Over 3.3V — raise top to 18kΩ (revised row below)
WHITE (PA0) revised | 18kΩ | 4k7Ω | 0.2073 | 3.32V | ✓ safe to 3.3V rail
BLACK (PA1) | 22kΩ | 4k7Ω | 0.1760 | 2.82V | ✓ safe to 3.3V rail

If the track PSU can deliver up to 16V, use R8=18kΩ (not 15kΩ) for the WHITE sense divider. Update WHITE_DIV_NUM/DEN in brake_module.h to 47/234 accordingly. The original 15k value was sized for 12.4V supplies; at 16V it produces 3.82V on PA0 which exceeds the 3.3V ADC reference.

## 3.4 Safe default behaviour

On power loss or MCU fault, the brake FET (Q2) must default to ON (hard brake). This is achieved by a pull-up resistor on the Q2 op-amp buffer input. When the MCU is unpowered, the buffer output rises to the braking region and Q2 conducts.

- When the rails die, R_SAFE (100kΩ from Q2 drain to gate) couples the coasting motor’s back-EMF on BLACK_to_track to the gate, turning Q2 on in proportion to car speed, while D_SAFE (Zener gate-to-source) clamps the gate. The result is a passive, self-limiting back-EMF brake — firm at speed, fading as the car slows, and off when the car is stationary — not a fixed linear hold.
- brake_force_safe() writes directly to the DAC registers and is called from hard_fault_handler and nmi_handler.
- The hold-up capacitor (C_HU 100µF on 3.3V rail) maintains MCU power for ~300ms after PSU cut, allowing the firmware to maintain the full programmed brake characteristic through power-off.

## 3.5 Power and thermal analysis

The following analysis confirms component ratings against the worst-case electrical demands of the application. Track PSU: 12.4V nominal, 16V maximum. Motor startup: 40A for a few milliseconds. Braking back-EMF: 20A+ momentarily. PSU cannot absorb reverse current.

Component | Worst-case demand | Rating | Verdict | Action taken
Q2 TW100N03CC (brake FET) | Linear operation. Worst-case mid-range (Rds ≈ motor R): ~12W peak, intermittent (~10–20% brake duty). HEATSINK REQUIRED — see 7A.8. Low-Rds logic-level part (e.g. TW100N03CC, ~3mΩ): full-on for brushless, linear for the brushed tables — see §7A.11–7A.12 for the effectiveness/thermal and linear-SOA analysis (which supersede the ~12W IRFP250N figure above). | ≥30V, ~3mΩ logic-level, SMD power package + heatsink | ✓ Comfortable | No change. Motor startup current (40A) does not flow through Q2 — Q2 is OFF during throttle. Copper pour under D2PAK pad recommended.
Q1 TIP147 (anti-brake current source) | Anti-brake current source (3A): pass device drops ~full rail at stall ≈ 47W worst case (transient, not continuous). HEATSINK REQUIRED — see 7A.8. TIP147 PNP Darlington (or N-MOSFET); D4 blocks reverse current. | 18A, 55V, 175°C Tj hFE ≈ 1000 (PNP Darlington). At stall Q1 is linear with VCE ≈ full rail — the source of the ~47W; VCE(sat) ≈ 2.5V applies only when saturated (low VCE), not when sourcing into Q2’s short | ✓ OK (with D4) | D4 mandatory in mode C. Without D4, body diode of Q1 carries 46A repetitively at 20kHz — not rated for this. D4 blocks this current path. The 47W is only the brief brake-onset transient (motor still spinning, high back-EMF); a sustained stall must be prevented in firmware by collapsing the KA demand when V_BLACK fails to rise — validate against the TIP147 DC-SOA on the bench.
D1 TVS (P6KE18CA) | Motor back-EMF adds to rail: 16V + 12V peak = 28V transient Energy: <<600W × 1ms pulse capacity | 600W peak (10/1000µs), Vc=25.2V @ 1A | ✓ OK | Changed to bidirectional CA variant. Unidirectional P6KE18A only clamps one polarity; inductive switching generates both.
D2/D3 SS310 (catch diodes) | Q2 turn-off spike: L × dI/dt = 100µH × 20A/1µs = 2000V unclamped D2 clamps at Vf + Vdc ≈16.4V, energy = 20mJ | 3A avg, 100V, same SMB footprint as SS34 | ✓ Upgraded | Changed from SS34 (40V) to SS310 (100V). D2 is essential — without it Q2’s 40V Vds is instantly exceeded on turn-off. 40V reverse rating left no margin on 16V rail. (The 100µH used for the turn-off spike is a deliberate worst-case; typical slot motors are 10–50µH, so the real dI/dt overshoot is lower — diode margin intentional.)
D4 MBRS360 (mode C series diode) | Series reverse-block diode (D4) on the current-source injection path. Carries the anti-brake injection current (up to 3A). | 3A avg, 60V, 150A peak (single pulse) Same SMB footprint | ✓ Upgraded | Changed from SS34 (80A peak, marginal under repetitive 20kHz stress) to MBRS360 (60V, same SMB footprint). SS54 (5A, 150A peak) is equally suitable. D4 position is the most electrically stressed diode in the design.
F1 polyfuse (WHITE rail) | MCU + LDO + gate drivers ≈ 35mA total on WHITE rail No motor current on WHITE rail during braking or throttle | Resettable fuse, now 500mA–1A | ✓ Corrected | Downrated from 25A to 500mA–1A. F1 protects the MCU/LDO supply on WHITE only. It must NOT be in the BLACK (track) path which carries 40A motor startup and 20A braking current — a polyfuse would trip.
U2 AMS1117-3.3 (LDO) | Load: ~35mA P = (16 − 3.3) × 0.035 = 0.44W at 16V rail ΔT = 0.44 × 62 = 27°C (SOT-223, no heatsink) | 1A, 125°C Tj, Rth_ja 62°C/W | ✓ OK | Tj = 52°C at 25°C ambient, 97°C at 70°C ambient. Both within 125°C limit. Solder SOT-223 tab to copper pour for better thermal performance.

Motor startup current of 40A does not flow through any module component during normal operation. Q2 and Q1 are both OFF when the hand controller is delivering power (V_BLACK > 1500mV). The module is fully passive during throttle. Only during braking does current flow through Q2, and only then does the back-EMF need to be managed.

## 3.6 User interface — control devices

The module has three physical control devices and a digital display. All are on or attached to the module enclosure. No modification to the hand controller is required.

[Figure 2: User interface controls and display logic — see AART_Brake_UI.svg]

Control | Type | Connector | Function
Mode toggle | 3-position switch | PB0 (bit 0), PB1 (bit 1) | Selects Mode A (brake only, all motors — KA floor from Mode C applied if set), Mode B (brushed anti-brake, lookup table), or Mode C (brushless KA tuning, save on leaving). Read each 1ms tick.
Potentiometer | 10kΩ linear rotary, no centre detent | PA3 (ADC_IN3) | Mode A: linear CCW→CW brake only (DAC_BRAKE_SOFT to DAC_BRAKE_HARD). Mode B: indexes coupled brake+anti-brake table. Mode C: dials KA floor live (CCW=0V, CW=~2V). No centre detent required.
BOOT0 button (J12) | Momentary pushbutton, normally open | PA14-BOOT0 (G0; nBOOT_SEL=0) | TM1637 DIO entry for field firmware update. Not part of normal operation.

## 3.6.1 What the potentiometer controls in each mode

The pot function depends on the mode selected by the toggle. In all modes, CCW gives minimum output and CW gives maximum:

Mode | Pot function | Output produced
Mode A — Brake only (all motors) | Linear map: CCW = selected soft min (SET BRAKE_OHMS, one of 25/15/5/4/3/2/1Ω), CW = DAC_BRAKE_HARD (dead short). No lookup table. | Q2 brake only. Q1 applies saved_ka_dac as a floor independently (set via Mode C). No anti-brake in Mode A.
Mode B — Anti-brake (brushed only) | Indexes brake_tables[][] and ka_dac_table[] simultaneously. Both brake and anti-brake live from single pot position. | CCW = min brake + max anti-brake (~2V). CW = max brake + no anti-brake. Coupled by table design.
Mode C — KA tuning (brushless, setup mode) | Dials KA floor live: CCW = DAC_KA_OFF (no floor), CW = DAC_KA_MAX (~2V). Display shows KA voltage. | Toggle away from Mode C → 500ms debounce → save saved_ka_dac + LED blinks 3×. Return to Mode A for racing.

Brake ramp-in time and trail release time are UART-only parameters (SET RAMP_MS and SET RELEASE_MS_A/B/C). They cannot be set with the pot. This keeps the pot free for the voltage setpoint function in all modes.

## 3.6.2 Mode C keep-alive floor procedure

Mode C keep-alive floor procedure:

- 1. Toggle to Mode C. The display switches from track voltage to the live KA floor voltage.
- 2. Rotate the pot to the desired KA floor level. CCW = 0V (no floor). CW = ~2V floor. The display tracks it live.
- 3. Toggle back to Mode A (or Mode B). After 500ms the floor is saved to flash. LED blinks 3×.
- 4. Mode A now applies the saved KA floor. Pot governs brake linearly. Car is ready for brushless racing.

What is saved and how it is applied:

Mode | What is saved | How it is applied
A | saved_ka_dac (KA floor, set by pot on leaving Mode C) | Q1 activates whenever V_BLACK drops below this voltage. 0 (DAC_KA_OFF) = no floor, pure braking. Set via Mode C.
B | No saved value in Mode B | Mode B uses the lookup table directly. Pot CCW = min brake + max anti-brake. No separate saved value.
C | N/A — Mode C is a tuning mode only | Mode C sets the value used in Mode A. It does not apply KA floor itself during racing.

All saved values survive power cycles. They are stored in page 31 of flash (0x08007C00) and loaded at boot. The firmware defaults to DAC_KA_OFF (no injection, no floor) if no valid flash record is found.

## 3.7 Digital display (TM1637)

A TM1637 4-digit 7-segment LED module connects to header J14, driven directly by the MCU over a 2-wire serial link (CLK on PB4, DIO on PB8). The MCU sends the exact digits to display, so there is no analog proxy and no scaling — the readout shows true values in real time. Specify a TM1637 module with per-digit decimal points (not the colon-only clock variant).

State | Display shows | Source signal
Normal running (Mode A or B) | Track supply voltage (WHITE rail), 0–16V | MCU formats V_WHITE (e.g. 14.2) and clocks it to the TM1637
Mode C active (KA tuning) | Live keep-alive floor voltage, 0–2V | MCU formats the live KA floor (e.g. 0.30) and clocks it to the TM1637

## 3.7.1 J14 connector pinout (TM1637)

Pin | Signal | Connect to module
1 | CLK — TM1637 clock (PB4) | Clock wire to module CLK
2 | DIO — TM1637 data (PB8, bidirectional) | Data wire to module DIO
3 | GND | Ground wire to module GND
4 | +3.3V (Vcc) | Power wire to module VCC

The display shows true values in both modes: the WHITE rail voltage (0–16 V, one decimal) while running in Mode A or B, and the live keep-alive floor (0–2 V, two decimals) while tuning in Mode C. Because the MCU drives the digits directly over the TM1637 serial link, no analog scaling or RC filter is involved; the previous PB4-PWM proxy and its TIM3 channel are removed.

# 4. Firmware Architecture

## 4.1 File structure

File | Description
Core/Inc/brake_module.h | Constants, pin map, mode/state enums, BrakeCtx_t, public API. Rev 11.
Core/Src/brake_module.c | Full control logic: clock/GPIO/DAC/ADC/DMA/display setup, flash load/save, mode state machine, brake_tick().
Core/Inc/uart_debug.h | DebugParams_t struct, uart_debug public API.
Core/Src/uart_debug.c | UART telemetry, SET/GET command parser, flash SAVE.
Core/Src/main.c | Top-level: SysTick ISR, fault handlers, main loop calling brake_tick().
stm32g051k6.ld | Linker script: 32K flash at 0x08000000, 18K RAM at 0x20000000. Page 31 reserved for NV storage.
Makefile | Docker build: arm-none-eabi-gcc, -DSTM32G051, libopencm3 linked.

## 4.2 Timing and scheduling

The module uses a polling architecture. brake_tick() is called from the main loop as fast as possible. A millisecond counter incremented by SysTick ISR provides internal pacing. ADC conversions run via DMA so the CPU never blocks waiting for a result. All control decisions happen in the 1ms tick context.

## 4.3 ADC configuration

ADC1 is configured in scan mode with three channels in sequence:

- Rank 1 — PA0 (CH0): WHITE rail voltage sense (R8/R9 divider)
- Rank 2 — PA1 (CH1): BLACK_to_track voltage sense (R10/R11 divider, track side of the pass switch)
- Rank 3 — PA3 (CH3): pot wiper (10k linear, 0–3.3V)

Results are transferred to a 3-element DMA buffer. DMA TC interrupt sets s_adc_ready flag. brake_tick() reads the flag and processes one set of readings per call. Trigger: software (SWSTART), retriggered at end of each DMA transfer.

## 4.4 DAC configuration

Both DAC channels are used — DAC1 for the brake gate (Q2), DAC2 for the anti-brake demand (Q1):

- DAC_CH1 (PA4) — Q2 brake gate. 0–3.3V linear, maps from the selected minimum resistance (25/15/5/4/3/2/1Ω) to dead short at the FET.
- Anti-brake / keep-alive demand is a DC voltage from DAC2 (DAC_OUT2 on PA5), fed through the demand divider and GD3 translator to the GD1 current-source op-amp. The DAC2 code sets the demand (0 = off, full = ~3A); see §7A.7.

Both channels use software trigger mode. brake_tick() calls set_brake_dac() and set_ka_dac() which write to DAC_DHR12R1/R2 and fire DAC_SWTRIGR. The op-amp buffers (GD1, GD2) buffer the DAC output to drive the FET gates in linear mode.

## 4.5 Key constants

Constant | Value | Description
DAC_BRAKE_OFF | 0 | Q2 off. 0V gate, Vgs < Vth.
DAC_BRAKE_SOFT | 1860 | Legacy reference (~1.5V gate, ~8Ω). Superseded by SET BRAKE_OHMS table selection.
DAC_BRAKE_HARD | 3095 | Q2 near dead short (~2.5V gate).
DAC_KA_OFF | 0 | Q1 off (DAC2 code 0 — no anti-brake injection).
DAC_KA_MAX | 2480 | Q1 maximum conduction (~60.6% duty → ~2V filtered demand → ~3A).
DAC_BRAKE_SOFT | see SET BRAKE_OHMS (idx 0–6, default 4) | Minimum brake resistance is selectable via SET BRAKE_OHMS (snaps to 25/15/5/4/3/2/1Ω), choosing one of seven stored tables. brake_ohms_idx (0-6) stored in flash. Default index 4 (~3Ω).
DAC_KA_MAX (anti-brake max) | 2480 (DAC_KA_MAX) | Maximum Q1 conduction. Anti-brake level follows pot via ka_dac_table[].
KA_SAVE_DEBOUNCE_MS | 500 | KA save debounce after leaving Mode C. Fixed at 500ms in firmware.
RAMP_MS_MAX | 200 | Maximum ramp-in time. SET RAMP_MS 0–200.
RELEASE_MS_MAX | 500 | Maximum trail release time. SET RELEASE_MS_A/B/C 0–500.
FLASH_MAGIC | 0xAA270008 | Rev 11. Old records invalidated on first boot.
FW_ID_STRING | AART-BRAKE-v11-STM32G051 | Returned by GET ID.

## 4.6 Control flow

brake_tick() runs the full state machine each call. The flow:

- 1. Read ADC DMA buffer — white_mv, black_mv, pot_raw.
- 2. Read toggle. Detect mode transitions — specifically leaving Mode C (triggers 500ms debounce save timer).
- 3. Latvian brake check — WHITE dV/dt. If triggered, apply DAC_BRAKE_HARD and return.
- 4. Update brake_active: read I_DIR (PA6) first — if asserted (reverse current = controller braking), force brake_active = true and hold it (IDIR_HOLD_TICKS) across brief reverse-detect dropouts; otherwise apply V_BLACK hysteresis (BRAKE_ENTER/EXIT_MV on BLACK_to_track) for coast entry and forward-drive exit.
- 5. Dispatch to mode handler: Mode A (linear brake + KA floor), Mode B (anti-brake table), or Mode C (KA tuning).
- 6. Mode A: linear map pot → Q2 brake, saved_ka_dac applied as Q1 floor when V_BLACK low. Mode B: table lookup for both outputs. Mode C: live ka_dac_table preview on the display, linear brake during braking.
- 7. If leaving Mode C and 500ms has elapsed: save ka_dac_table[pot_idx] as saved_ka_dac, blink LED 3×.
- 8. Update display: track voltage normally; live ka_dac_table value while in Mode C.
- 9. Update LED blink state.

# 5. Bench Testing

## 5.1 Brake detection verification

Inject a variable DC voltage on the BLACK_to_track node via a bench supply or potentiometer. Observe UART telemetry state field:

- V_BLACK < 500mV → state transitions to BRAKING (or RAMP_IN if ramp enabled)
- V_BLACK > 1500mV → state returns to PASS
- Between 500mV and 1500mV → state holds (hysteresis prevents chatter)

## 5.2 Power budget

Production target at 4MHz LP Run mode: approximately 524µA total. MCU ~372µA, op-amp buffers ~50µA each, LDO (MCP1700) 2µA quiescent. Hold-up capacitor C_HU 100µF sustains MCU for >300ms after PSU cut. See section 7A.6 for full analysis.

# 6. Open Items and Known Limitations

Item | Description | Status
Q1 anti-brake current source | Superseded. The anti-brake stage is now a DAC2-set constant-current source (section 7A.7). The floating-supply circuit (ZD1/R_Z1/C_Z1/LM321) is removed. | Resolved by redesign — anti-brake is now a DAC2-set constant-current source (section 7A.7). Remaining bench items: current-source loop stability and pass-device heatsink sizing (~47W transient at stall).
Pass-switch control polarity | INA210/LM311 reverse threshold (~0.16A) and hysteresis, the gate-drive charge pump, and the reverse response time (~2µs) — verify on bench before PCB (section 7A.2). | Open — bench verify.
Latvian brake primary trigger | WHITE dV/dt detects PSU cut and car-out-of-slot events. Implemented in current firmware (STATE_LATVIAN_BRAKE). Threshold configurable via SET LATVIAN_DVDT. Disabled by default (0 = off). The alternative trigger (BLACK braid loss) was considered but WHITE dV/dt covers both PSU cut and out-of-slot and is sufficient. | Implemented. UART-configurable threshold (SET LATVIAN_DVDT). Closed.

# 7A. Production Architecture — Design Decisions and Analysis

## 7A.1 Overview

This section documents the key architectural decisions made during the design process, the alternatives considered, and the rationale for each choice.

## 7A.2 Reverse-blocking pass element — two N-channel bidirectional switch

Design change (this revision). The BLACK controller-input path needs a low-loss element that passes the controller’s drive to the track with minimal insertion drop but blocks reverse current (track voltage or motor back-EMF feeding back into the controller output). Earlier options — an NPN level-shift, a P-channel + driver, and an LTC4412/ideal-diode IC — are all retired. The anode-powered ideal-diode-IC approach fails for two reasons specific to this circuit, both identified in review:

- Bootstrap/startup region: an ideal-diode controller draws its power from the anode (the BLACK line). Until BLACK rises above the controller’s minimum operating voltage, the controller is unpowered and cannot enhance the FET, so the pass FET’s body diode carries the current — ~1V drop at several amps — in exactly the low-throttle region where the racer modulates most.
- Turn-on discontinuity: as BLACK crosses the controller’s turn-on threshold, the series drop collapses from ~1V (body diode) to ~20mV (regulated) almost instantly. The motor sees that ~1V step for a tiny trigger movement — a dead/notchy zone that an ISRA-level racer would feel immediately.

## 7A.2.1 Topology — common-source N-channel pair

Two N-channel MOSFETs are placed in series back-to-back with their sources tied together (common-source). Drains go to the two BLACK terminals (controller side and track side); the common source is the driver reference node. The opposing body diodes mean the switch blocks in both directions when off and conducts with low Rds(on) in both directions when on, so turning it off blocks reverse current. P-channel is deliberately avoided: at 40A its on-resistance (best-in-class ~6–12mΩ at these voltages) would add 0.2–0.5V of drop and 9–20W of heat, defeating the low-drop requirement. N-channel hits sub-milliohm.

## 7A.2.2 Driver — INA210 + LM311 ideal diode (sense and compare on +5V, gate drive from WHITE)

Design change (this revision). The reverse-block driver is now an ideal diode built from a TI INA210 current-sense amplifier (U5) and an LM311 comparator (U6), replacing the TPS1212-Q1 of the previous revision. The INA210 (gain 200) senses the main-path current across the shunt Rsns_sw; the LM311 compares its output to a small threshold and turns the Q5/Q6 common-source pair off when the current reverses. The INA210 and LM311 run from the +5V analog rail — not the anode — so they are alive regardless of the BLACK voltage, sidestepping the bootstrap problem of anode-powered ideal-diode ICs.

- VS (supply) ties directly to the WHITE rail. Its operating range is 3.5–73V (74V absolute max), so 12–16V is well inside it and no VCC clamp is needed (the LTC7001 required one; this part does not). Control is alive regardless of BLACK voltage — same bootstrap fix as before, fewer parts.
- Why the INA210 + LM311 ideal diode over the TPS1212-Q1: the motivation is the motor-current glitch when the brake contact closes. The TPS1212’s ~6–10µs reverse response let ~29A flow for ~13µs (≈377A·µs) and dragged the motor voltage down enough to risk browning out and restarting the brushless eCom — the very thing the keep-alive exists to prevent. The faster ideal diode (~2µs, ~0.16A trip, ~50mV hysteresis) cuts the glitch to ~13A for ~2.2µs (≈29A·µs, ~13× lower energy) and a much smaller voltage dip. The cost is the TPS1212’s integrated protection — I²t overcurrent, 5µs short-circuit, IMON, FLT — which the ideal diode does not provide. This is an accepted open item: none of the other stages (brake, anti-brake) carry protection either and the reverse event is brief, but the pass FETs lose their own fault protection. A second open item is the gate drive: the common-source N-FET gates must be lifted above the 0–16V BLACK node — the TPS1212 did this with an internal charge pump, so the ideal diode needs a discrete high-side gate driver / charge pump fed from WHITE and gated by the LM311.

Because the LM311 turns the whole Q5/Q6 pair off on a reverse event, the opposing body diodes then block in both directions — so the same two FETs give true bidirectional reverse blocking. A single FET could not (its body diode would conduct the blocked direction), which is the reason the back-to-back pair is retained.

## 7A.2.3 Reverse-current sensing, trip threshold, and response speed

The INA210 senses main-path current across the shunt Rsns_sw and presents a ground-referenced voltage (gain 200) to the LM311. The LM311 compares this against a threshold set just above the zero-current point and asserts its reverse-detect output when current flows in reverse; that output both turns the gate driver off (FETs block) and feeds the MCU brake-detect on PA6. With Rsns_sw ≈ 1mΩ the threshold is ~0.16A — INA210 ±35µV offset plus the LM311’s 50mV hysteresis ÷ 200 ≈ ±160µV, ÷ 1mΩ — versus ~±0.6A for the TPS1212’s ±2%-of-30mV monitor.

## 7A.2.3.1 Reverse-response speed and the eCom-brownout motivation

The driver behind this whole change is the motor-voltage glitch when the brake contact closes mid-run. With the TPS1212’s ~6–10µs reverse response the brake-contact closure let a ~29A spike flow for ~13µs and pulled the motor voltage down noticeably — short in human terms, but enough to risk the brushless eCom seeing a brownout and restarting. The INA210 + LM311 ideal diode reaches ~2µs in simulation, cutting the spike to ~13A for ~2.2µs and the voltage dip with it, roughly 13× less glitch energy. Two caveats on the speed: the ~2µs figure must be confirmed with the real INA210 and LM311 models (the INA210 at gain 200 is bandwidth-limited and zero-drift, so it trips on the rising edge rather than at full settling), and the INA210’s 26V common-mode ceiling — versus the TPS1212’s 73V — must be checked against any track transient at the shunt node.

## 7A.2.3.2 Sense resistor and insertion drop

The INA210 wants a defined shunt Rsns_sw. Sizing it at ~1mΩ gives ~40mV at 40A and the ~0.16A reverse threshold above; combined with the two FETs (2 × 0.59mΩ ≈ 47mV) the total insertion drop is ~87mV at 40A. Rsns_sw is a drop-vs-resolution knob: a smaller shunt lowers the drop but coarsens the threshold. The lossless Vds-sense of the previous revision is not available — the INA210 needs the real shunt — and the bidirectional IMON readback of the TPS1212 is gone, though the INA210’s own output is an analog current signal that can be routed to a spare ADC if a readback is wanted.

Note: The INA210 is a zero-drift current-sense amplifier (gain 200, common-mode −0.3 to 26V, ±35µV offset); the LM311 is a fast bipolar comparator. Watch the INA210/LM311 footprints and pinouts, the Kelvin connection at Rsns_sw, the LM311 hysteresis network, and the gate-drive charge pump (open item). Bench-verify the reverse trip threshold, the reverse-detect-to-off time (~2µs target), and the 26V common-mode headroom at 40A before PCB. The LM311 output to the gate driver must be fast and fail-safe (reverse → off).

## 7A.2.4 Device selection and insertion-drop budget (40A)

- Q5, Q6 — 40V N-channel, very low Rds(on). Candidates: ST STL059N4S8AG (0.59mΩ, PowerFLAT 5×6) or Vishay SiJK140E (0.34mΩ, PowerPAK 10×12). Two in series.
- Insertion drop at 40A: 2 × 0.59mΩ ≈ 47mV across the FETs, plus the shunt Rsns_sw (~1mΩ ≈ 40mV), for ~87mV total. Higher than the bare-FET 47mV, the price of the reverse sense. With Vishay SiJK140E (0.34mΩ) the FET part drops to ~27mV.

Note: At sub-milliohm, PCB copper resistance is a real fraction of the total path. A few cm of 1oz copper is itself ~0.5mΩ, so the insertion-drop budget must include the layout: wide pours, short runs, and Kelvin-sensed comparison points. Budget the whole series path (connector + braid + FET pair + copper) against the target, not just the silicon. Bench-verify the drop at full 40A and confirm comparator turn-off speed prevents reverse current.

## 7A.3 Linear mode FET control

Both Q1 and Q2 operate in their linear (triode) region rather than as switches. This eliminates PWM switching noise on the braid, which is critical for brushless eCom compatibility. It also removes 20kHz conducted emissions that would complicate CE marking. See section 11.0 for full analysis.

## 7A.4 Hold-up capacitor sizing

A 100µF SMD electrolytic on the 3.3V rail provides ~300ms MCU hold-up after PSU cut at 524µA production load. This ensures the firmware maintains the full programmed brake through the power-off transient. See section 7A.6 for worked calculation.

## 7A.5 Production MCU: STM32G051K6U6

- QFN-32 — provides all required GPIO and DAC peripherals.
- 12-bit DAC (PA4/PA5) — required for linear gate voltage control.
- 32KB flash, 18KB RAM, 64MHz Cortex-M0+ — adequate for Rev 11 firmware.
- Available at JLCPCB. Not a special-order part.

## 7A.6 Power-down, brownout and hold-up capacitor

## 7A.6.1 The problem: braking must survive PSU power-off

A conventional brake resistor continues to brake the car when the PSU cuts because it requires no power. An active module loses MCU power at PSU cut. The pull-up on GD2 provides a hardware safe default (Q2 enters braking region), but the hold-up capacitor extends firmware-controlled braking through the transient.

## 7A.6.2 STM32G051 power supply supervisor: POR, PDR and BOR

Circuit | Function | Threshold | Behaviour on VDD falling
POR (Power-On Reset) | Holds MCU in reset during power-up | VPOR ≈ 1.7V (rising) | Not relevant on falling edge
PDR (Power-Down Reset) | Resets MCU when VDD falls below minimum | VPDR ≈ 1.6V (falling) | MCU reset. DAC outputs collapse.
BOR (Brownout Reset) | Programmable earlier warning threshold via option bytes | VBOR1–VBOR4: 1.7V–2.8V selectable | MCU reset when VDD < VBORx

## 7A.6.3 Why the STM32G051 has suitable power consumption

Component | Prototype (64MHz) | Production (4MHz) | Notes
STM32G051 MCU | ~6mA | ~372µA | G0 family: ~93µA/MHz. 4MHz × 93 = 372µA.
Gate drivers GD1/GD2 | ~0.05mA (op-amp buffers) | ~50µA (op-amp) | Dominant saving. Linear mode op-amps replace switching drivers.
LDO | ~5mA (AMS1117) | ~2µA (MCP1700) | AMS1117 quiescent is 5mA. MCP1700 is 2µA.
ADC, DAC, GPIO | ~500µA | ~100µA | ADC scanning 3 channels at 1ms interval.
Total | ~21.5mA | ~524µA | Production well under 1mA.

## 7A.6.4 Hold-up capacitor sizing — worked calculation

C = I × t / ΔV, where I = 524µA, t = 100ms, ΔV = 3.3 − 1.7 = 1.6V:

- C = 0.000524 × 0.1 / 1.6 = 32.8µF minimum
- Use 100µF (3× margin). Verification: t = 100×10⁻⁶ × 1.6 / 0.000524 = 305ms.
- 3× margin accounts for X5R/X7R capacitance derating at DC bias (−40% typical), age degradation, and load estimate uncertainty.

## 7A.6.5 Component selection: 100µF 6.3V SMD electrolytic

Parameter | Value | Rationale
Capacitance | 100µF | >300ms hold-up at 524µA, 3× margin
Voltage rating | 6.3V min, 10V preferred | Reduces derating on 3.3V rail
Package | SMD electrolytic or 1210 polymer | Polymer SMD has lower ESR
Stored energy | E = ½CV² = 0.54mJ | Powers MCU only. Well below any regulatory stored-energy threshold.

The 100µF hold-up cap is in addition to the ST-recommended 100nF + 4.7µF decoupling at VDD pins.

## 7A.6.6 Behaviour on power-down

Time | Event | MCU state | Brake output
t = 0 | PSU switched off. WHITE rail begins to fall. | Running normally | Programmed brake at pot-set level
t ≈ 0–10ms | LDO ceases to regulate. C_HU supplies VDD. | Running from capacitor | DAC maintains programmed brake
t ≈ 0–305ms | VDD falls from 3.3V toward 1.7V as C_HU discharges. | Running. ADC less accurate below 2V. | Programmed brake maintained
t ≈ 305ms | VDD < PDR threshold. MCU resets. DAC collapses. | Reset | Pull-up circuit takes over
t > 305ms | R2 pull-up holds Q2 gate in braking region. | No power | Hardware safe-default brake

## 7A.7 Anti-brake stage — constant-current source (DAC2-set, 3A)

Design decision (this revision). The anti-brake demand is generated by DAC2 (DAC_OUT2 on PA5), not a filtered PWM. Earlier revisions used a 50 kHz TIM2_CH1 PWM plus an RC filter (C_KA) on the same pin, which freed DAC2 but left it unused. DAC2 delivers clean 12-bit DC straight into the demand divider and GD3 translator: it deletes C_KA and its series R, removes a switching node, and makes both analogue outputs DAC writes (DAC1 = brake gate, DAC2 = anti-brake demand) — finally using the dual DAC the STM32G051 was chosen for (§7C). The divider and GD3 are unchanged; they are required because GD1 is WHITE-referenced.

Design change (this revision). The anti-brake stage is a constant-current source, not the voltage follower of the previous revision. Real transistor controllers (Kobic and similar) implement anti-brake as a current source — typically 2.5–3A at maximum, set by the pass transistor’s gain — not a fixed voltage. The follower was wrong for the case that matters most: a car stationary on the start line presents a near short-circuit, so a voltage follower holding ~2V into it would drive an unbounded current (tens of amps, limited only by the device SOA). A current source bounds the injection to ~3A regardless of motor impedance, which is both the correct behaviour and what a racer’s muscle memory expects.

## 7A.7.1 Topology (per the SIMetrix design)

A classic high-side op-amp current source. The op-amp drives the pass device and regulates the voltage across a sense resistor in the supply leg to equal the demand, so the load current is held constant at I = Vdemand / Rsense independent of the motor:

- Op-amp supply — CRITICAL: GD1 is powered from the WHITE rail (~12–16V), NOT the +5V rail. Because the sense resistor sits in the WHITE leg, the op-amp’s inputs and output sit at a common mode near the rail (~16V); a 5V op-amp cannot sense or drive there. GD1 must also be rail-to-rail INPUT, because it senses right at V+ — an LM358/LM321-class part will NOT work (its input common-mode range stops ~1.5V below V+ and cannot reach the rail). Use the TI LM7321 (RRIO, 2.5–32V, SOT-23); for higher precision the OPA192 is an alternative. The op-amp output swings near WHITE to drive the TIP147 base. Only the GD2 brake buffer remains on the +5V rail; unlike GD1 it needs rail-to-rail OUTPUT (not input) and a gain of ~1.5 to lift the 3.3V DAC to a ~5V gate drive — the same LM7321 covers it (budget alternative for GD2 only: TLV9061 — which is RRO but not rail-to-rail input, so it cannot serve GD1). The +5V supply also conveniently caps the gate at ~5V — full-on for the low-Rds FET and safe for a logic-level gate. Both are the same LM7321 type but two separate singles, since GD1 (WHITE) and GD2 (+5V) sit on different rails; a dual LM7322 could combine them only if both ran on one rail.

Note: This corrects an earlier revision that placed GD1 on +5V. It is confirmed by the SIMetrix design (AntibrakeConstCurrent.wxsch), where the op-amp V+ ties to the supply rail (V3) and it senses just below it.

- Rsense = 0.1Ω in the WHITE-rail leg of the pass device. At 3A that is 0.3V across it (0.9W).
- Demand is a DC voltage from DAC2 (DAC_OUT2 on PA5), divided to a 0.30V ground-referenced reference (R_KA1 6.8k / R_KA2 1.2k), then translated to the WHITE rail by GD3 (a unity-gain difference amplifier) so the current-source demand is WHITE − 0.30V. The MCU sets the DAC2 code from the single control-pot reading (PA3 → ka_dac_table[]); there is no second pot and no pot in the current-source loop itself. Code 0 → 0A (off); full → 3A.

Worked ceiling (DAC count → current): with R_KA1 = 6.8 kΩ and R_KA2 = 1.2 kΩ the demand divider R_KA2/(R_KA1+R_KA2) = 1.2/8.0 = 0.15 scales the DAC2 output, so I_max = (DAC_KA_MAX/4095 × 3.3 V) × 0.15 / Rsense = (2480/4095 × 3.3 V) × 0.15 / 0.1 Ω = 2.0 V × 0.15 / 0.1 Ω = 0.30 V / 0.1 Ω = 3.0 A. GD3, a unity-gain difference amplifier, then translates this 0.30 V demand to the WHITE-side node (WHITE − 0.30 V) that GD1 regulates.

- Pass device: TIP147 PNP Darlington (TO-220 + heatsink) as the primary choice — a bipolar pass element is robust in linear operation. An N-channel MOSFET (SUP70060E, or RFP50N06 / FDP61N20 / SUP50020EL) is the documented alternative; at our low Vce/Vds (≤16V) the SOA is power-limited, so either works.

The current setpoint is generated by DAC2 as clean DC, feeding the demand divider and GD3 translator. The op-amp and Rsense form the loop; the pass device supplies the current. The injection still goes through D4 (MBRS360) into the motor node, blocking reverse current from the track.

## 7A.7.2 Why a current source is also safer

- Shoot-through protection: if a fault turns the brake (Q2) and anti-brake on together, a current source caps its contribution at ~3A instead of feeding a near-short — a genuine fault-tolerance property the follower lacked.
- Add open/short detection on the current-source loop itself, plus a fast over-current trip, to guard against a component failure in the source turning it into an uncontrolled path.

## 7A.7.3 Firmware impact

Anti-brake demand is a DAC2 code, written to DAC_DHR12R2. The ka table maps pot index → DAC code (0 = off … full = 3A); polarity is 0 = off, so the "KA off = 0" convention holds. DAC1 drives the brake gate (linear gate voltage for resistance control); DAC2 drives the anti-brake demand. The DAC_KA_OFF/DAC_KA_MAX constants are now literal DAC codes.

## 7A.8 Thermal — anti-brake pass device (worst case at stall)

At stall the motor is ~0V, so the pass device drops nearly the full rail at the set current. Using the steady-state SOA method (Tj = Ta + Pd·(Rθjc + Rθcs + Rθsa)) from the SIMetrix design, with Vsupply(max) = 16V and Ta = 30°C. Past the junction there are two series terms beyond Rθjc (junction-to-case, datasheet): Rθcs, the case-to-sink thermal-interface material (§7A.8.1), and Rθsa, the heatsink’s sink-to-ambient resistance. Their sum is the case-to-ambient Rθca = Rθcs + Rθsa, so the heatsink actually specified is Rθsa = Rθca − Rθcs, not Rθca itself:

- At Iout = 2.75A → Pd ≈ 44W (no tolerance). TIP147: SOA 125W at Tc=25°C, allow Tj=125°C, Rθjc=1°C/W → required Rθca = (125−30)/44 − 1 = 1.16°C/W, giving Tc ≈ 81°C.
- SUP70060E (MOSFET): SOA 200W, allow Tj=150°C, Rθjc=0.75°C/W → Rθca = (150−30)/44 − 0.75 = 1.98°C/W, Tc ≈ 117°C. The MOSFET allows a smaller heatsink but runs hotter (or the same heatsink at a cooler Tj).
- At the full 3A demand the worst case rises to Pd ≈ 47W, tightening the TIP147 case-to-ambient budget to Rθca ≈ 1.0°C/W. With a realistic grease interface (Rθcs ≈ 0.5°C/W for a non-isolated TO-220, §7A.8.1) the heatsink itself must then be Rθsa ≈ 0.5°C/W — roughly twice the sink the bare Rθca figure implies. Design the heatsink to the 3A figure with the interface included.

## 7A.8.1 Case-to-heatsink interface (thermal interface material)

The case-to-ambient term above is not the heatsink alone: it is the interface Rθcs in series with the heatsink Rθsa. The interface path is case → contact resistance → bulk TIM → contact resistance → sink, and on a small package the two contact resistances often outweigh the bulk. Omitting Rθcs is optimistic — against the ~1°C/W case-to-ambient budget an interface of 0.3–0.5°C/W is 30–50% of the total.

The bulk part alone is Rθ_bulk = L / (λ·A): L the bond-line thickness (m), λ the TIM conductivity (W/m·K), A the contact area (≈90 mm² for a TO-220 tab, ≈150 mm² for TO-247). Two cautions. L is not a value you set — it is whatever surface flatness, mounting pressure and paste rheology leave, typically 25–100 µm and unknown without measuring. And the formula ignores the two contact resistances, so it underestimates badly: for ordinary grease it returns roughly a quarter of the real figure (λ=4 W/m·K, L=50 µm, A=90 mm² → ~0.14°C/W versus a measured ~0.5°C/W).

So do not size the interface from λ. Use the TIM datasheet’s measured Rθcs / thermal-impedance where given — it already includes the contact resistances, though it is quoted at a stated mounting pressure and worsens at lower pressure. Otherwise take a conservative tabulated value for the package-plus-TIM, or measure it: drive a known Pd and read Rθcs = (Tc − Ts)/Pd.

Representative Rθcs for a non-isolated TO-220 (no mica or insulating pad), mounted with pressure: dry ≈ 1.0–1.2 (never run dry); ordinary silicone grease ≈ 0.5; high-conductivity grease (λ≈3–5 W/m·K) ≈ 0.3; phase-change film (e.g. Honeywell PTM7950, λ≈8.5 W/m·K) ≈ 0.2 °C/W. An electrically-insulating interface would add roughly +0.3 to +1°C/W, but the TIP147 tab carries the collector and is not isolated here, so a bare grease or phase-change interface is correct. A TO-247 part, with more contact area, roughly halves these.

Folded into the 3A worst case (Pd ≈ 47W → Rθca ≈ 1.0°C/W): ordinary grease (Rθcs 0.5) needs a heatsink of Rθsa ≈ 0.5°C/W; a good phase-change film (Rθcs 0.2) relaxes it to Rθsa ≈ 0.8°C/W — a real change in sink size. Phase-change films also apply more cleanly than paste and, reflowed once under spring pressure, give a thin repeatable bond-line, preferable for production if a current part is sourced. Note the interface sits in the junction’s fast path (Rθjc + Rθcs) ahead of the sink mass, so it raises peak Tj directly and is not hidden by the burst-energy argument below.

These are steady-state numbers and therefore conservative. Anti-brake is active only in short bursts, so the heatsink’s thermal capacitance can be factored in: for a burst much shorter than the sink’s thermal time constant, the rise is set by capacitance, ΔT ≈ Energy / Cth, not by Rθca. A ~50g aluminium sink has Cth ≈ 0.05kg × 900 J/kg·°C ≈ 45 J/°C, so a 2s, 47W burst (≈94J) lifts it only ~2°C before it cools between launches. So the practical heatsink can be smaller than the steady-state Rθca implies — size it from the worst-case burst energy and the racing duty cycle, not continuous 47W.

Note: Both the brake FET (Q2 (TW100N03CC), section 7A.8 prior content folded here) and the anti-brake pass device run linear and need heatsinks. Confirm the actual anti-brake active time per lap on the bench to set the heatsink via the pulse-energy method above.

## 7A.9 USB-C interface — UART bridge and auxiliary power

A USB-C connector is added to provide two functions: a UART terminal connection to a laptop or PC for issuing SET/GET commands and monitoring telemetry, and auxiliary power to the module when the track is not connected (bench configuration, parameter setting before a race).

## 7A.9.1 New components

- J_USB — USB-C receptacle, 16-pin SMD (HRO TYPE-C-31-M-12 or equivalent, JLCPCB). Carries VBUS, GND, D+, D−, CC1, CC2. Mid-mount or top-mount.
- U3 — CH340N USB-UART bridge, SOP-8 (JLCPCB C506813, ~€0.15). Internal 12MHz clock, no crystal required. Supports 3.3V supply.
- R_CC1, R_CC2 — 5.1kΩ 0402 each, CC1 and CC2 to GND. Required for USB-C DFP detection (signals to host that this is a UFP device and requests 5V/0.9A).
- D_USB — BAT54 Schottky diode, SOT-23 (or equivalent, JLCPCB). VBUS in to LDO input, prevents reverse current from track WHITE rail reaching the USB host.
- F_USB — 500mA polyfuse 0805, in VBUS line before D_USB. Protects USB host from shorts on the module.
- C_USB1 — 10µF 10V MLCC 0805, VBUS decoupling.
- C_USB2 — 100nF 0402, CH340N VCC decoupling.

## 7A.9.2 Power supply arrangement

The module has two power inputs: the track WHITE rail (12–16V) and USB VBUS (5V). Both feed the existing LDO (U2) input through protection diodes:

- WHITE rail → F1 (polyfuse, existing) → D_WHITE (SS310 Schottky, existing) → LDO input
- VBUS → F_USB (polyfuse, new) → D_USB (BAT54 Schottky, new) → LDO input

Both diodes OR into the LDO input. The higher voltage dominates: WHITE (12–16V) always has higher voltage than VBUS (5V) so WHITE powers the LDO when both are connected. The LDO output is 3.3V in both cases.

USB host protection: D_USB blocks the WHITE rail voltage from reaching the USB host. The USB host sees only its own VBUS through F_USB. There is no path from WHITE to VBUS. This is the critical isolation requirement and it is met by the series Schottky.

Note: When only USB is connected (no track), VBUS supplies the LDO at 5V. The LDO regulates to 3.3V normally. The module is fully functional for UART configuration. The FET gate drivers and FETs are not powered (WHITE = 0V) but the MCU and UART run normally.

## 7A.9.3 CH340N wiring

The CH340N is configured for 3.3V operation (V3 pin shorted to VCC, both at 3.3V):

- VCC (pin 8) → 3.3V rail
- V3 (pin 1) → VCC (shorted, enables 3.3V I/O mode)
- GND (pin 2) → GND
- D+ (pin 3) → USB-C D+
- D− (pin 4) → USB-C D−
- RXD (pin 5) → MCU PA9 (USART1_TX). CH340N receives what MCU transmits.
- TXD (pin 6) → MCU PA10 (USART1_RX). CH340N transmits to MCU.
- Unused pins (7, 8) left unconnected or tied per datasheet

Note: CH340N batch numbers > B40 include internal backflow prevention. For earlier batches, a series Schottky on RXD prevents current injection into the MCU when the MCU is unpowered but USB is connected.

## 7A.9.4 USB-C connector wiring

- VBUS (pins A4, B4) → F_USB → D_USB → LDO input
- GND (pins A1, B1, A12, B12) → GND
- D+ (pins A6, B6) → CH340N pin 3
- D− (pins A7, B7) → CH340N pin 4
- CC1 (pin A5) → R_CC1 (5.1kΩ) → GND
- CC2 (pin B5) → R_CC2 (5.1kΩ) → GND
- SBU1, SBU2, SSTX, SSRX: not connected (USB 2.0 only)

## 7A.9.5 Driver installation

The CH340N requires a driver on the host computer. On Linux and macOS (10.9+) the ch341 kernel module is included and loads automatically. On Windows 10/11 the driver is available from the WCH website (www.wch-ic.com). Once installed the module appears as a standard COM port (Windows) or /dev/ttyUSBx (Linux) or /dev/tty.wchusb* (macOS). Any serial terminal at 115200 8N1 can then issue UART commands.

## 7A.10 Configurable minimum brake resistance

The minimum braking resistance (the resistance at pot CCW, the gentlest brake setting) is motor-dependent and spans a wide range. A small brushless motor might need as little as 1Ω, while a conventional brushed motor used for scale-model racing might want as much as 25Ω. The original hardcoded ~8Ω (DAC_BRAKE_SOFT = 1860) suited neither end of that range well. This value is now selectable at runtime — the 25/15/5/4/3/2/1Ω table via SET BRAKE_OHMS — without being hardware-dependent.

## 7A.10.1 Why stored tables, not runtime scaling

Two implementations were considered. The first rescaled a single base table on every control tick to move its soft endpoint. The second — adopted here — stores five precomputed tables, one per nominal resistance, and selects one by index. The stored-table approach was chosen because it performs zero arithmetic on the table in the control loop: the 1ms tick is a pure array lookup, keeping timing fully deterministic and avoiding any floating-point or division on the Cortex-M0+ (which has no FPU).

## 7A.10.2 The seven tables

Seven brake tables are stored, each a gamma-1.8 curve from its soft endpoint up to DAC_BRAKE_HARD (dead short). The resistances are spaced non-linearly (25, 15, 5, 4, 3, 2, 1Ω — coarse at the gentle end, dense at the firm end where small changes matter most) so the steps are finer at the firm/low-ohm end where small changes matter most, and coarser at the gentle end. Higher DAC = higher Q2 gate voltage = lower Rds(on) = lower resistance, so lower-ohm settings use higher soft endpoints:

- Index 0 — ~25Ω full scale (gentlest minimum brake; e.g. hardbody homeset 1/32)
- Index 1 — ~15Ω full scale
- Index 2 — ~5Ω full scale
- Index 3 — ~4Ω full scale
- Index 4 — ~3Ω full scale (default)
- Index 5 — ~2Ω full scale
- Index 6 — ~1Ω full scale (firmest minimum brake)

Mode B (anti-brake) indexes the selected table directly. Mode A and Mode C (linear maps) use the selected table’s soft endpoint as the CCW value of map_u16. The anti-brake (ka_dac_table) is unaffected — it is a voltage injection, independent of brake resistance.

## 7A.10.3 UART command and storage

- SET BRAKE_OHMS <ohm> takes the requested resistance and snaps to the nearest stored table (25/15/5/4/3/2/1Ω). Takes effect immediately; SAVE persists it.
- The selected index (0-6) is stored in flash DW2 (replacing the former brake_soft_dac slot).
- GET reports the current setting as brake_ohms=N.
- Default on first boot or after flash erase: index 1 (~3Ω).

## 7A.10.4 Calibration

Note: The 1-5Ω labels are nominal estimates. True effective resistance at a given gate voltage depends on the specific FET, its temperature, and the instantaneous braking current, and cannot be computed in firmware. The per-step soft DAC endpoints are deliberately left as calibration placeholders in this revision. The earlier values were anchored to an 8Ω≈1860 estimate that proved far too low (25Ω brake pots are used for hardbody homeset 1/32 cars), so every endpoint must be measured on the bench with the target FET (IRFP250N) and motor and then committed via tools/gen_brake_tables.py.

To calibrate: select each setting with SET BRAKE_OHMS, measure or feel the actual braking behaviour with the target motor under load, and if the endpoints need adjustment, edit OHM_LABELS / SOFT_ENDPOINTS in tools/gen_brake_tables.py, regenerate the tables, and rebuild the firmware. This keeps the runtime path free of any table arithmetic while allowing precise per-motor tuning.

## 7A.9.6 Firmware update over USB-C

No custom bootloader is required to update firmware over the USB-C connection. The STM32G051 contains a factory bootloader in system ROM that cannot be erased and supports firmware loading over USART1 (PA9/PA10) — the same pins the CH340N bridge is wired to. A single USB-C cable to a host PC is therefore sufficient to reflash the module.

Important distinction: this is the ROM UART bootloader reached through the USB-to-UART bridge, not native USB DFU. The STM32G051 has no USB device peripheral (USB appears only on the larger G0B1/G0C1 parts), so the module does not enumerate as a DFU device. From the host side the workflow is identical to any serial flash: open the CH340N COM port and use stm32flash or STM32CubeProgrammer in UART mode.

## 7A.9.7 CH340N reset limitation and update procedure

The CH340N is the minimal 8-pin variant and does not expose the DTR/RTS modem-control lines that auto-reset circuits use. The bootloader entry therefore cannot be automated from the flashing tool; it is performed manually with the BOOT0 (J12) and NRST (J13) buttons already present in the design:

- Connect the USB-C cable to the host PC. The module appears as a COM port (/dev/ttyUSB* on Linux, /dev/tty.wchusb* on macOS).
- Hold BOOT0 (J12) high, press and release NRST (J13), then release BOOT0. The MCU starts in the TM1637 DIO, listening on USART1.
- On the host, flash the image: stm32flash -w aart-brake.bin -v /dev/ttyUSB0 (or STM32CubeProgrammer in UART mode). Baud is auto-detected from the 0x7F sync byte.
- Press and release NRST again (BOOT0 now low). The new firmware runs.

Note: If automatic, button-free updates are ever required, a small application bootloader could be added that is triggered by a UART command (e.g. ENTER_DFU), receives the new image, and jumps to it. This costs flash, a partitioned memory map, and the usual brick risk of a self-update path, so it is not used here — the ROM UART bootloader with manual BOOT0/NRST is the lower-risk standard route for occasional updates.

Note: Before PCB commit, confirm against ST application note AN2606 that the TM1637 DIO USART maps to PA9/PA10 on the specific STM32G051 variant used. This holds for the G0x1 family but is worth a quick verification, as a mismatch would prevent the CH340N bridge from reaching the bootloader.

## 7A.10.5 How brake and anti-brake are encoded in the table

In Mode B a single pot position drives two outputs simultaneously. The coupling is purely positional: the pot reading is reduced to one 8-bit index, and that index reads two parallel 256-entry tables at the same time — one for the brake FET (Q2), one for the anti-brake / keep-alive FET (Q1).

The decode runs every 1ms tick and contains no arithmetic or interpolation:

idx = pot_raw >> 4; // 12-bit ADC -> 8-bit index

brk_dac = brake_tables[active_ohms_idx()][idx]; // Q2 gate drive

ka_dac = ka_dac_table[idx]; // Q1 anti-brake demand (DAC2)

Both stored values are 12-bit DAC codes (0–4095), i.e. gate-drive levels that become gate voltages through the op-amp buffers. They are not ohms or volts directly — the mapping from a DAC code to an actual resistance or injection voltage is FET-, temperature- and current-dependent and must be calibrated on the bench.

The two tables are built to sweep in opposite directions, so rotating the pot trades one output for the other:

- Index 0 (pot full CCW): brake at its soft minimum, anti-brake at maximum (ka_dac ≈ 2480, ~2V forward injection).
- Index 255 (pot full CW): brake at dead short (3095), anti-brake off (demand = 0, Q1 off — DAC2 current source).
- Higher brake DAC = higher Q2 gate voltage = lower Rds = more braking. Higher anti-brake DAC = more injection. The two are applied in different phases — Q2 brakes while the trigger is in the brake zone, Q1 injects while running (after brake exit) — both indexed by the same pot position, so one pot sets the balance.

The brake curve uses a gamma-1.8 shape giving fine resolution at the soft end; the anti-brake curve fades to zero before full CW (by default at about 65% of pot travel) so the firmest part of the brake range carries no injection at all.

## 7A.10.6 Are separate tables per resistance necessary?

The five stored brake tables currently share the same gamma shape and differ only in where their soft (CCW) endpoint sits. Strictly, that is redundant: the shape is one table and the per-resistance part is just five endpoint values. Two factorings are valid:

- Five full tables (current design): ~2.5KB of flash (brake 2560 B + shared anti-brake 512 B + labels/endpoints 20 B ≈ 3.1KB). Buys zero runtime math and the freedom to give each resistance a different curve shape later.
- One shape + five endpoints, scaled at runtime: ~512 B plus ten endpoint values, at the cost of one multiply and one divide per tick in Mode B. Trivial on the M0+, but it reintroduces the runtime table arithmetic the stored-table design was chosen to avoid.

Because flash is not tight (32KB total, ~12KB used) and there is a plausible future need to give the low-ohm brushless profiles a distinct brake or anti-brake feel, the five-table form is retained. The redundancy is only redundancy while every profile keeps the same shape — the moment any profile diverges (a sharper brake curve, an earlier anti-brake fade), the separate tables stop being redundant. If all profiles are guaranteed to stay identical in shape, the single-shape-plus-endpoints form is the more honest choice.

Per-profile anti-brake tables are also supported (one ka_dac_table per resistance instead of a shared one), raising the cost to about 5.1KB — only worth it if the injection profile must differ by motor type.

## 7A.10.7 Table generation and inspection tooling

Two Python tools accompany the firmware (in firmware/tools/). They are the authoritative way to regenerate the tables after bench calibration:

- gen_brake_tables.py — builds the C source (brake_ohms_label[], brake_soft_dac_by_ohm[], brake_tables[][] and the anti-brake table). Each resistance is described by a Profile with independent knobs for both curves: brake_soft and brake_gamma shape the brake sweep; ka_max, ka_gamma and ka_zero_at shape the anti-brake sweep and set where injection fades to zero. Run with --per-profile-ka to emit independent anti-brake tables. The script prints the exact flash cost of the chosen configuration.
- test_brake_tables.py — reproduces the firmware decode (pot >> 4 -> index -> two lookups) and reports the brake and anti-brake DAC values at any pot setting, with rough physical estimates. Use --ohms N --pot P for a single point or --sweep for the full travel.

Calibration workflow: select a profile, measure the real braking and injection behaviour with the target motor under load, adjust that profile’s endpoints or gamma in gen_brake_tables.py, regenerate, and rebuild. This keeps the runtime path a pure lookup while allowing precise per-motor tuning.

Note: The ohm and injection-voltage figures printed by test_brake_tables.py are interpolations from hand-set anchor points, not measurements. The DAC codes are exact; the physical readouts are orientation only until calibrated on the bench.

## 7A.11 Braking physics — what “hard brake” means, and why the brake FET must be very low Rds

Braking the car means shorting the motor. A spinning motor is a generator: shorting its terminals lets its back-EMF drive a current back through the windings, and that current produces the retarding torque. The brake current is I = V_bemf / (R_motor + R_brake + R_wiring), and the retarding torque is proportional to it. In this module R_brake is Q2’s channel resistance (Rds): Q2 places that resistance across the load (low-side, the BLACK-to-track node to RED), so a “hard brake” is the low-resistance end — Q2 driven toward its minimum Rds.

The two motor types this module serves sit at very different points on that curve, and the brushless case dominates (≈80% of expected use, ISRA classes):

- Brushed motor (≈1.4 Ω winding): R_motor is the dominant term. Any reasonable brake resistance is a small fraction of the loop, so the brake is essentially motor-limited and the hardest brake is ≈ V_bemf / 1.4 Ω.
- Brushless motor (31–273 mΩ phase): the brake module shorts the on-car Remora ESC’s DC bus, and the motor brakes by pushing its back-EMF through the Remora’s body-diode rectifier into that short. The loop is roughly two phases in series (~60–550 mΩ), plus the ESC’s two body-diode drops, plus Q2’s Rds. Crucially, that motor resistance is BELOW the brake FET’s own on-resistance — so the brake stops being motor-limited and becomes FET-limited.

Figure 7A.11 (left) makes the consequence explicit. “Brake effectiveness” is how close the achieved brake current gets to a perfect zero-ohm short, η = R_motor / (R_motor + R_brake), independent of speed. In the brushless band: the IRFP250N at a 5 V gate (~300 mΩ) is only 9–48% effective — most of the brake is lost in the FET; at a 10 V gate (~75 mΩ), 29–78%; a single-digit-milliohm logic-level FET fully on (~3 mΩ) reaches 91–99%. For the brushed 1.4 Ω motor the IRFP250N is fine (82–100%). The IRFP250N is thus the right device for the case that is shrinking and the wrong device for the case that dominates.

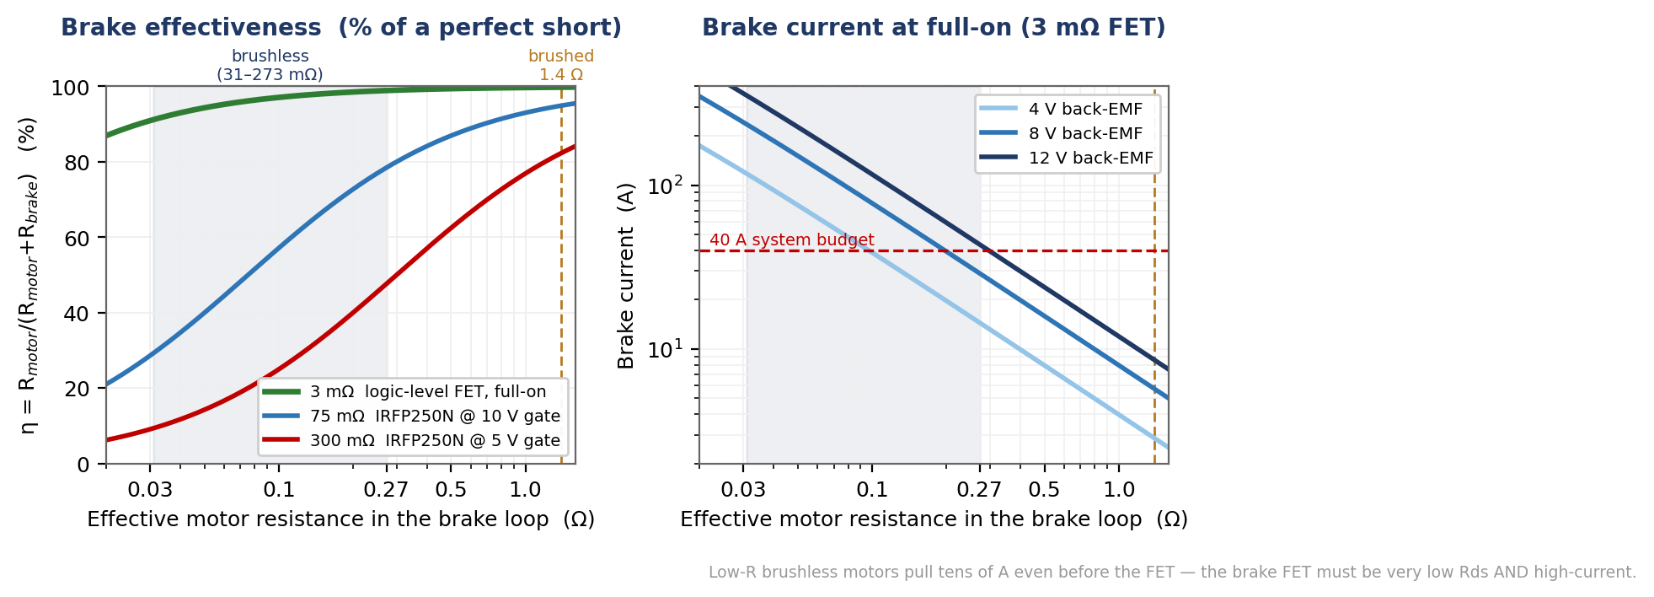
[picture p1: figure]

Figure 7A.11 — Left: brake effectiveness (% of a perfect short) vs the effective motor resistance in the brake loop, for three brake-FET options; the shaded band is the brushless phase-resistance range (31–273 mΩ), the dashed line the brushed motor (1.4 Ω). Right: brake current for a 3 mΩ FET fully on, at three back-EMF levels — low-resistance brushless motors pull tens of amps, into the 40 A budget. Effectiveness is speed-independent; the current panel scales with back-EMF.

It is also a thermal necessity, not just an effectiveness one. At these low resistances the brake current is tens of amps (the 40 A system budget is exactly this regime). At 40 A a 3 mΩ FET dissipates I²R ≈ 4.8 W; the IRFP250N at 75 mΩ would dissipate ≈ 120 W in the device — it cannot sit in a brushless brake loop at all. The low-Rds FET is forced by both effectiveness and survival.

The brake FET (Q2) should therefore be a single-digit-milliohm logic-level N-channel device — the same class already used in the Remora power stage (TWGMC TW100N03CC ~3 mΩ, Allpower AP90N03Q, Vishay SiSS-series), driven fully on. For the brushless hard brake this is unambiguous: the FET is fully enhanced (ohmic), its linear-mode SOA is irrelevant, and GD2 on +5 V is sufficient to drive a logic-level gate. The tension is with the BRUSHED linear-resistance tables (§7A.10), which operate the FET in its linear region at a controlled Rds — where modern low-Rds trench FETs have much narrower forward-bias SOA than the planar IRFP250N. Two clean resolutions:

- (a) Validate the chosen low-Rds FET’s linear SOA at the brushed operating point (a few amps, a few volts) — the currents are modest, so a suitable part may be fine; or
- (b) Drive the brushed brake by PWM of the same low-Rds FET (always fully on or off, never linear), synthesising the effective resistance by duty. This abandons the original “linear, no switching” choice for the brushed mode, but removes any linear-SOA concern and lets one FET serve both motor types.

Because brushless is 80% of use, the device is chosen low-Rds first; the brushed linear behaviour is the secondary mode to satisfy by (a) or (b).

One brushless-specific caveat: because the brake works through the ESC’s body-diode rectifier, there is a low-speed dead-zone — the brake produces no current until the motor’s back-EMF exceeds the two series diode drops (~1.4–2 V). Below that speed the bus short does nothing and the car free-rolls the last little bit. Active phase-short braking in the Remora firmware would avoid this, but that is the ESC’s job, not this module’s.

The brushless inductance (2.5–11.7 µH per phase, ~doubled line-to-line) sets the brake transient: L/R at these low resistances is tens of microseconds, so current rises fast; stored energy ½LI² at 40 A is only ~10 mJ, but D2 (the catch diode) must now clamp a 40 A inductive kick on brake release, so its rating wants checking alongside the FET.

Decision: Q2 is selected as a single-digit-milliohm logic-level N-channel (Remora class, e.g. TW100N03CC), driven fully on for the dominant brushless hard brake; GD2 stays on +5 V. The legacy brushed linear-resistance tables are satisfied by keeping linear control: §7A.12 validates that a 30 V low-Rds FET is safe in linear at the brushed operating point (low Vds). The IRFP250N is retained only as an adequate option for brushed-only builds.

## 7A.12 Validating a low-Rds FET in linear mode (brushed brake tables)

Option (a) from §7A.11 keeps linear resistance control for the brushed tables, which requires the low-Rds FET chosen for the brushless full-on role to also survive linear-region operation. It does — because the brushed brake never drives the FET into the part of the SOA where low-Rds devices are vulnerable.

The brushed envelope is set by the motor (1.4 Ω) and Q2’s table Rds (1–25 Ω) forming a divider of the back-EMF (up to ~16 V at brake onset): Vds = V_bemf · R_brake/(R_motor+R_brake), I_D = V_bemf/(R_motor+R_brake), P = Vds·I_D. Worst-case dissipation is at the impedance match R_brake ≈ R_motor: at 16 V back-EMF that is ~8 V across Q2 at ~5.7 A, ~46 W — momentary (highest at brake onset, decaying as the car slows), at perhaps 10–20% duty per lap. Crucially the high-Vds points (soft tables) occur at near-zero current; the locus never combines high Vds with high current (Figure 7A.12).

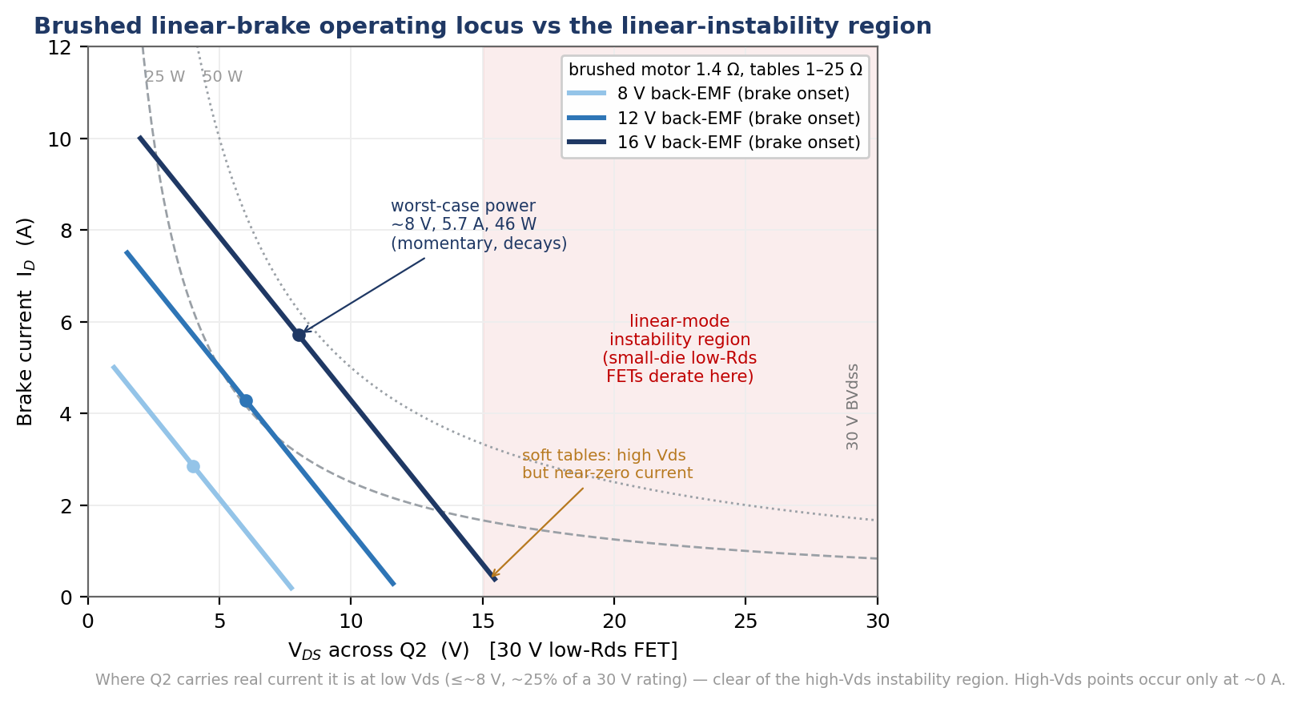
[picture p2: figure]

Figure 7A.12 — The brushed linear-brake operating locus (motor 1.4 Ω, tables 1–25 Ω) for three brake-onset back-EMFs, on a 30 V low-Rds FET. Where Q2 carries real current it sits at low Vds (≤~8 V, ~25% of the rating); the high-Vds soft-table points are at ~0 A. The locus stays clear of the high-Vds linear-mode instability region where small-die low-Rds FETs derate.

Why that is the safe answer: the SOA limit that penalises low-Rds FETs in linear mode is the thermal-instability (“Spirito”) line, not the simple thermal limit. Reaching low Rds needs a small die, so at high Vds the low-gate-overdrive cells show positive thermal feedback (a hot cell conducts more, hogs current, runs away) and the safe boundary drops below the constant-power line. This is exactly the failure mode the wide-SOA planar IRFP250N was chosen to avoid. But the instability is a high-Vds phenomenon — it bites in the upper part of the voltage rating, not at low Vds. On a 30 V part the brushed brake operates at ≤~8 V where it carries current (~25% of the rating), comfortably below the instability rolloff; the IRFP250N’s 200 V wide-SOA margin is for high-Vds linear operation this brake never approaches.

Validation result: a 30 V low-Rds logic-level FET is safe in linear at the brushed operating point — so the brake keeps linear (no-switching) control for brushed and full-on for brushless with one device. The only real constraint is the ordinary thermal limit (Tj from ~46 W peak, intermittent), handled by the existing heatsink.

Two provisos for the final part. Confirm its DC (or ≥100 ms) SOA covers ~(8 V, 6 A) — trivial for a 90–100 A device — and that its thermal-instability line sits above that point at the heatsink case temperature. The cheap slot-car FETs (TWGMC, Allpower) often do not publish a linear/DC SOA, so prefer a low-Rds part that does — a Vishay TrenchFET Gen V (e.g. SiSS54DN) or an Infineon OptiMOS — to make this a datasheet check rather than a bench gamble; then bench-confirm by holding the worst-case point on the heatsink for the longest brake duration at lap cadence and watching for any runaway. GD2 must also span the gate range that produces the table Rds values, with the safe-default still parking Q2 at brake-on.

# 7B. Key Design Decisions

Decision | Chosen approach | Alternative considered | Rationale
Q2 safe default behaviour | Pull-up on Q2 gate driver input drives Q2 into braking region when MCU off | No safe default; separate fail-safe circuit | Safe default is the passive R_SAFE/D_SAFE back-EMF brake: speed-proportional, self-limiting, and off when the car is stationary. Essential safety requirement.
Keep-alive suppression | Q1 off when V_BLACK > floor voltage derived from saved_ka_dac and white_mv | Continuous injection regardless of V_BLACK | Only floor below setpoint; no interference with controller above it.
Ramp shape (entry) | Exponential (geometric decay: brake_dac += error × alpha/256 per ms) | Linear ramp | Fast initial bite then gentle tail. Matches driver expectation on hard braking.
Anti-brake ceiling | 2V (DAC_KA_MAX=2480, ~2V at 12–16V rail) | Higher voltage | 2V is top of practical range for commercial controllers (0.2–2V typical). Set via Mode B lookup table — pot position determines anti-brake level at all times.
KA floor save timing | Mode C save on toggle-out after 500ms debounce | Immediate pot takeover | 500ms debounce prevents accidental saves from toggle contact bounce. No pot handback needed — Mode A pot is always live.
(reserved, was capture button) | No capture button in Rev 11. KA floor saved by toggle gesture (leaving Mode C). | ADC pin (original design, before PA4/PA5 were reassigned to DAC outputs) | Toggle-out is the natural gesture for mode change. No separate button needed. PB3 reserved for future use.
Flash storage | Four 64-bit double-words at page 31 (Rev 11). Magic 0xAA270008. | EEPROM emulation | G0 flash requires 64-bit aligned writes. Page 31 reserved by linker. Four DWs store all tuneable parameters.
MCU package | STM32G051K6U6 QFN-32 | G031 SOIC-8 | QFN-32 provides PA4/PA5 DAC outputs, PB0/PB1/PB3/PB4 GPIO, sufficient for all signals. G051 has 12-bit DAC required for linear mode.
Toggle positions | 3-position: A (brake all motors) / B (brushed anti-brake) / C (KA tuning) | 2-position or mode-less | Mode A is the racing mode for all motor types (brushed and brushless). Mode B adds coupled anti-brake for brushed. Mode C is KA tuning only — set the floor and return to Mode A.
Minimum brake DAC | Minimum brake resistance selectable via SET BRAKE_OHMS, snapping to one of seven non-linearly spaced stored tables (25/15/5/4/3/2/1Ω). No runtime table math. | Hardcoded minimum | Different motors need different minimum braking resistance (e.g. ~3Ω for a 1105 brushless, ~5Ω for Group 12 brushed). Storing seven tables avoids any per-tick table computation while keeping the choice field-selectable.

# 8. Firmware Build — libopencm3 and Docker Toolchain

## 8.1 Library choice

libopencm3 is used instead of STM32 HAL. It provides direct register-level access with thin C wrappers, no RTOS, no hidden interrupt overhead, and a deterministic build. The firmware has no dynamic memory allocation and no C++ dependencies.

## 8.2 G0-specific differences from other STM32 families

- Flash programming requires 64-bit double-word writes (flash_program_double_word). 32-bit writes are not supported on G0.
- DMA requests are routed via DMAMUX1. ADC1 uses DMAMUX request 5.
- DAC1 has two independent channels on PA4 (CH1) and PA5 (CH2). Both enabled simultaneously in the dac_setup() function.
- The project provides stm32g051k6.ld with MEMORY block: FLASH 32K at 0x08000000, RAM 18K at 0x20000000. Page 31 (last 1K of flash) is excluded from the FLASH region and reserved for NV parameter storage.

## 8.3 Docker toolchain

Build and flash are containerised. The Dockerfile installs arm-none-eabi-gcc and fetches libopencm3 as a git submodule at build time. This ensures a reproducible build environment independent of the host OS.

- docker compose run --rm brake build — compiles firmware to build/aart-brake.elf and build/aart-brake.bin
- docker compose run --rm brake flash — flashes via OpenOCD over SWD (ST-Link V2 or compatible)
- docker compose run --rm brake debug — starts OpenOCD GDB server on port 3333

## 8.4 Build workflow

After cloning: git submodule update --init --recursive (fetches libopencm3), then docker compose run --rm brake build. The build produces aart-brake.elf (with debug symbols) and aart-brake.bin (raw binary for UART bootloader upload). Binary size is typically 8–12KB of the 32KB flash.

# 9. Pre-Commissioning Checklist
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

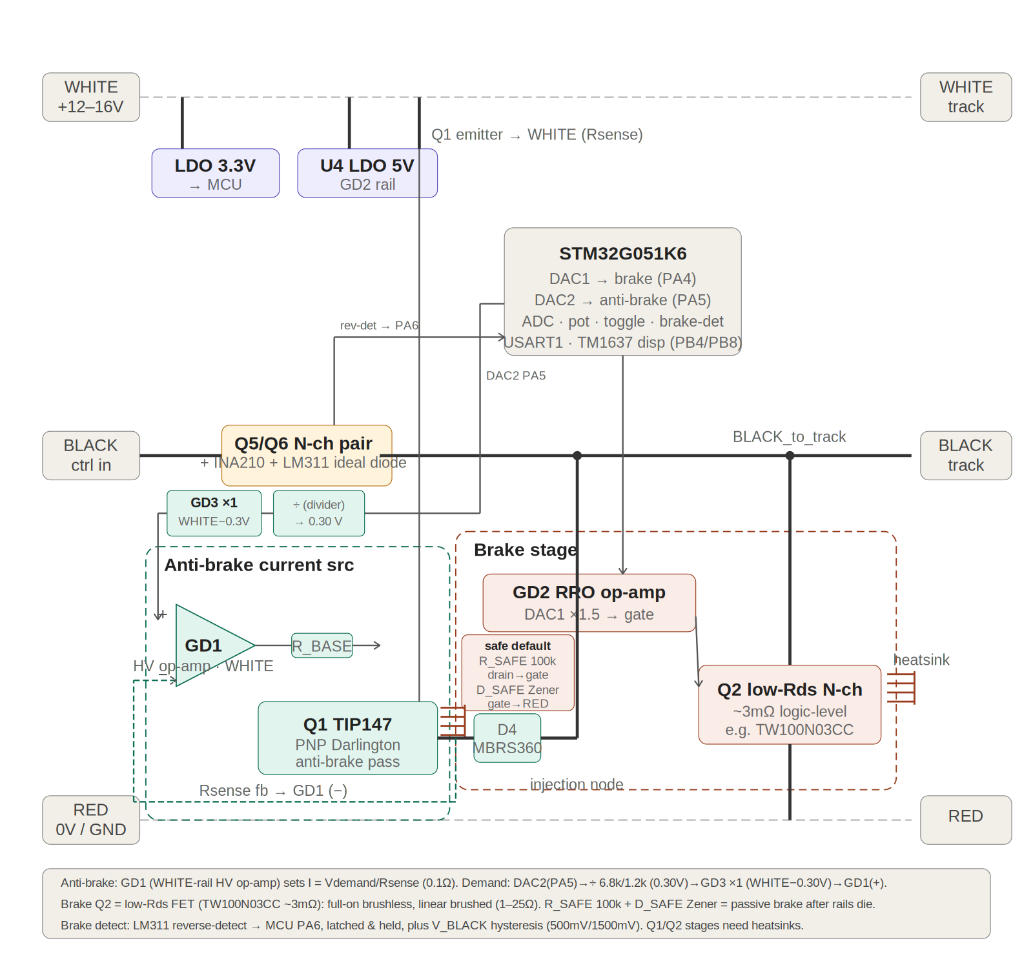
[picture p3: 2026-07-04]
AART_Brake_Topology.png

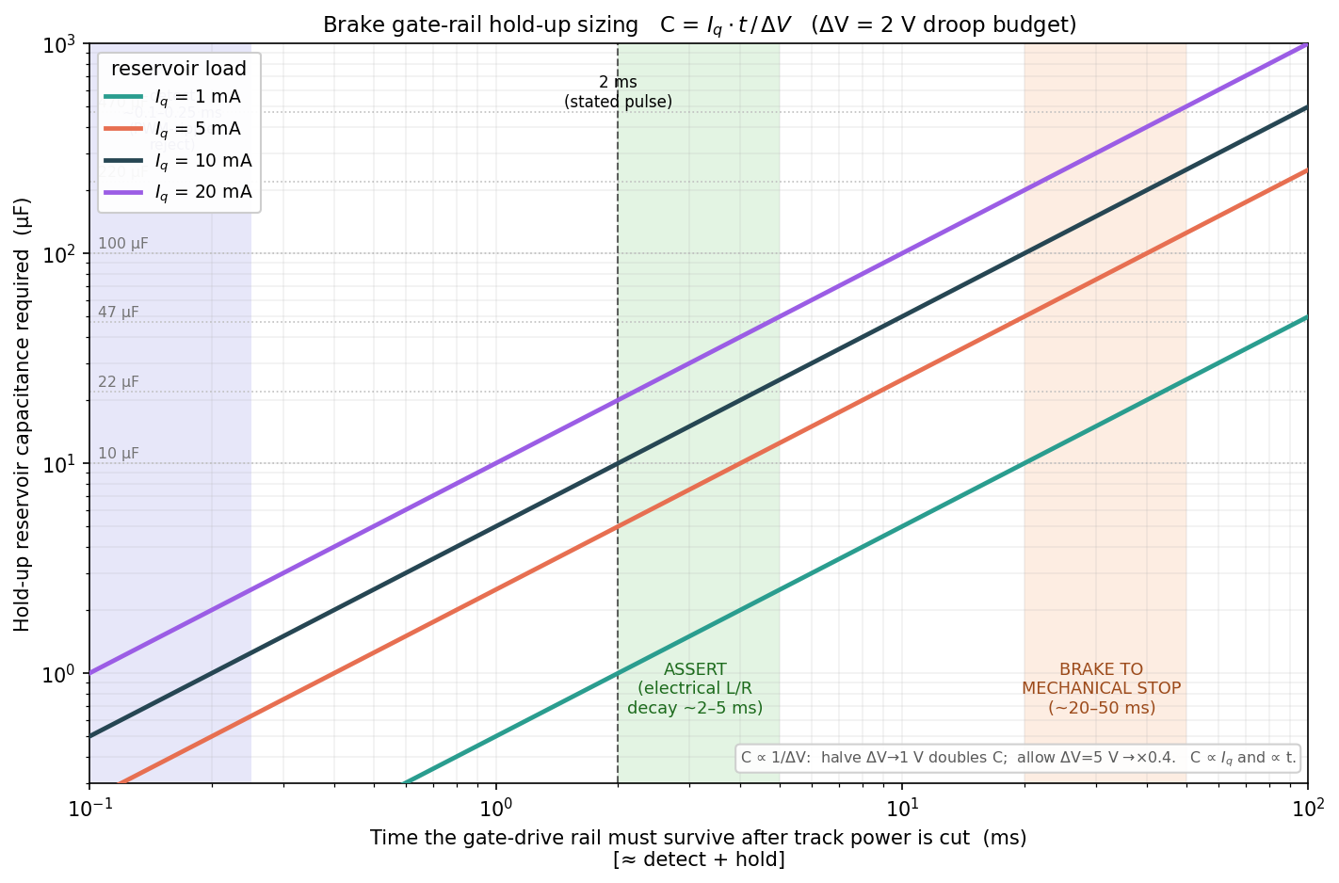
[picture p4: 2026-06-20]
brake_holdup_sizing.png

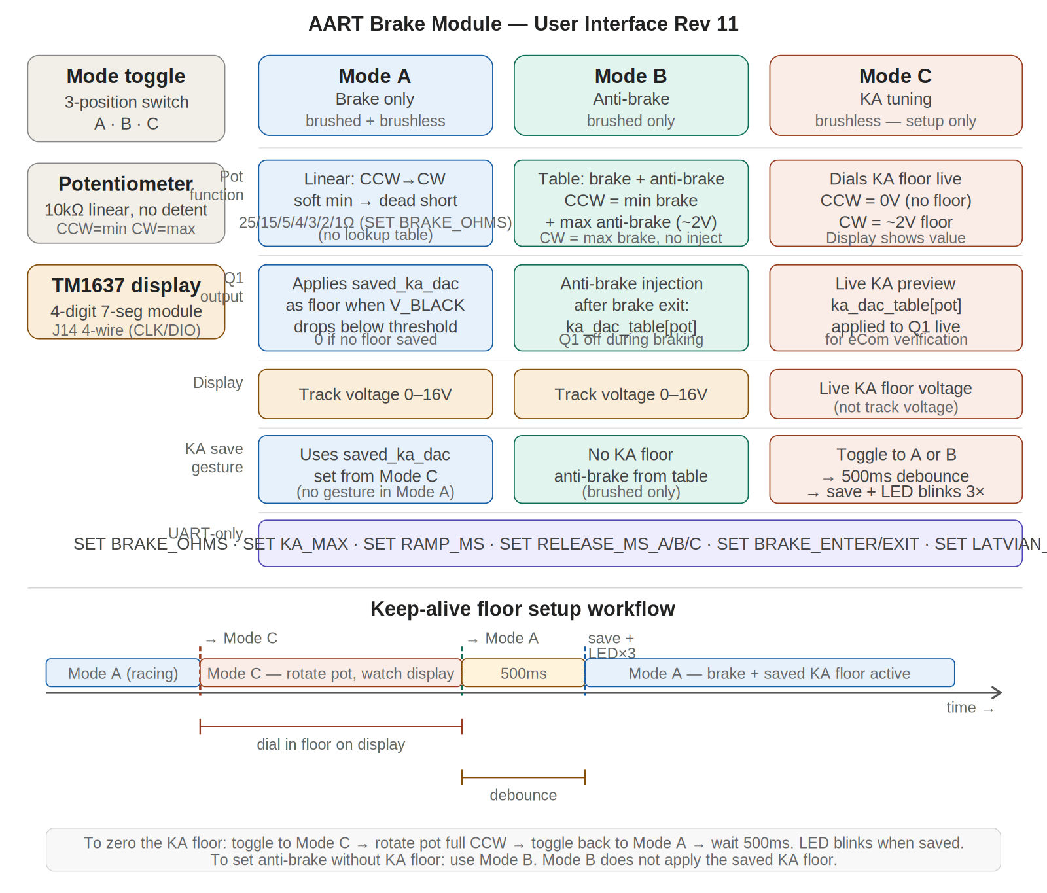
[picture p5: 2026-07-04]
AART_Brake_UI.png

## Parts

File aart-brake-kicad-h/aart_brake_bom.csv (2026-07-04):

Reference | Value | Description | Package | Quantity | Notes
U1 | STM32G051K6U6 | ARM Cortex-M0+ MCU 32K flash 8K RAM | QFN-32 5x5mm | 1 | Main controller. DAC1 brake (PA4); PWM anti-brake demand (PA5). Firmware Rev 11.
U2 | AMS1117-3.3 | LDO 12-16V to 3.3V (MCU rail) | SOT-223 | 1 | Or MCP1700-3302 (SOT-23) if low standby Iq needed; see design doc 7A.6.
U4 | MCP1700-5002 | LDO 12-16V to 5V (analog rail) | SOT-23 | 1 | Powers GD2 brake buffer only. GD1 anti-brake op-amp is on the WHITE rail.
GD2 | Op-amp (RRO) | Brake gate driver (DAC1 -> Q2 gate | linear) | SOT-23 (LM7321 single) | 1 | Non-inverting gain ~1.5 to lift 3.3V DAC to ~5V gate. Needs rail-to-rail OUTPUT. TI LM7321. NOTE: drives Q2 (TW100N03CC) logic-level gate; ~5V fully enhances for full-on brushless braking.
GD1 | Op-amp (RRIO HV) | Anti-brake current-source loop op-amp on WHITE rail | SOT-23 (LM7321 single) or half of LM7322 dual w/ GD3 | 1 | Regulates I=(WHITE-AB_DEMAND)/Rsense. LM7321 RRIO; alt OPA192.
U5 | TPS1212-Q1 | TI smart high-side switch controller (reverse block + protection) | VQFN-23 4x4 | 1 | VS from WHITE (3.5-73V | no clamp). GATE drives Q5/Q6. I_DIR reverse (~6-10us) + I2t OCP + 5us SCP + IMON/FLT. Replaces LTC7001+INA241+comparator (TI vs ADI; adds protection).
Q2 | TW100N03CC (Remora class) | Low-Rds logic-level N-ch brake FET (~3mohm 30V) | SMD power per Remora | 1 | PRIMARY for brushless (80%): braked full-on via Remora ESC bus - motor 31-273mohm needs single-digit-mohm Rds. IRFP250N (75mohm) gives only 9-78% brake + ~120W at 40A => brushed-only (TO-247 wide-SOA). Brushed linear tables: low-Rds FET VALIDATED in linear (brushed op pt ~8V Vds | clear of instability region). See 7A.12.
Q1 | TIP147 | PNP Darlington anti-brake current-source pass (100V 10A 125W) | TO-220 | 1 | Linear pass element ~47W transient at stall. HEATSINK REQUIRED. Alt: N-MOSFET SUP70060E / RFP50N06 / FDP61N20 / SUP50020EL.
Q5 | STL059N4S8AG | N-ch reverse-block FET (40V 0.59mohm) | PowerFLAT 5x6 | 1 | Common-source with Q6. Driven by U5 GATE. Alt: Vishay SiJK140E (0.34mohm).
Q6 | STL059N4S8AG | N-ch reverse-block FET (40V 0.59mohm) | PowerFLAT 5x6 | 1 | Common-source with Q5. Body diodes oppose -> block both directions when off.
RSNS | 0.5-0.75mohm | TPS1212 main-path current sense (CS1+/CS1-) | 2512 or shunt | 1 | ~20-30mV at 40A. Sets IMON/OCP. Drop-vs-accuracy knob.
Rsense | 0.1ohm 1-2W | Anti-brake current-source sense (WHITE leg) | 2512 | 1 | 0.3V at 3A. I = Vdemand / 0.1ohm.
D1 | P6KE18CA | TVS diode 18V BIDIRECTIONAL (WHITE rail clamp) | SMB (DO-214AA) | 1 | CA suffix essential. On WHITE rail only.
D2 | SS310 | Schottky 3A 100V (Q2 catch diode) | SMB (DO-214AA) | 1 | 100V for inductive turn-off spike headroom on 16V rail.
D4 | MBRS360 | Schottky 3A 60V (anti-brake reverse block) | SMB (DO-214AA) | 1 | In series with Q1 injection; blocks reverse current from track. Up to 3A.
D5 | LED Red | Status indicator (flash-save confirmation) | 0805 | 1 | Driven by PB6.
F1 | Polyfuse 500mA-1A | Resettable fuse — WHITE rail MCU/analog supply | 1812 | 1 | WHITE rail ONLY. Never in BLACK (40A) path.
C1 | 10uF 25V | LDO (U2) input bulk | 0805 | 1
C2 | 100nF 25V | LDO (U2) input HF | 0402 | 1
C3 | 10uF 10V | LDO (U2) output bulk | 0805 | 1
C4 | 100nF 10V | LDO (U2) output HF | 0402 | 1
C4b | 1uF 16V | LDO (U4) +5V rail decoupling | 0402 | 1
C5 | 100nF | MCU VDD decoupling | 0402 | 1
C6 | 100nF | MCU VDDA decoupling | 0402 | 1
C7 | 4.7uF | MCU VDDA bulk | 0402 | 1
C_BST | 100nF | TPS1212 BST-SRC bootstrap cap | 0402 | 1 | Per datasheet (min 0.1uF).
CI2t | 10nF | TPS1212 I2t breaker timer | 0402 | 1 | Sets overcurrent fault time.
CTMR | 1nF | TPS1212 retry/latch timer | 0402 | 1 | Leave for fastest | or set latch via resistor.
R2 | 10k | GD2 input pull-up (safe-default brake) | 0402 | 1 | On GD2 INPUT | not Q2 gate.
R3 | 10R | Q2 gate resistor | 0402 | 1
R_BASE | 1k | Q1 (TIP147) base resistor | 0402 | 1 | GD1 output to Darlington base.
R_KA1 | 6.8k | Anti-brake demand divider (top); with R_KA2 sets ratio 0.15 | 0402 | 1 | DAC2 output x0.15 = 0.30V demand at full code -> 3A.
R_KA2 | 1.2k | Anti-brake demand divider (bottom to GND); R_KA2/(R_KA1+R_KA2)=1.2/8.0=0.15 | 0402 | 1 | Sets 0.30V demand -> 3A via Rsense 0.1ohm.
RIOC | per design | TPS1212 OCP threshold set (IOC) | 0402 | 1 | Sets overcurrent comparator threshold (~50-60A trip).
R5 | 10k | Pot top-end to 3.3V | 0402 | 1
R8 | 18k | WHITE sense top divider (PA0) | 0402 | 1
R9 | 4k7 | WHITE sense bottom divider (PA0) | 0402 | 1
R10 | 22k | BLACK sense top divider (PA1) | 0402 | 1 | Tap on TRACK side of reverse switch.
R11 | 4k7 | BLACK sense bottom divider (PA1) | 0402 | 1
R12 | 330R | Status LED current limit | 0402 | 1
J1-J6 | 4mm banana | Track + controller WHITE/BLACK/RED (x2 sides) | banana socket | 6 | Module inserts between controller and track.
J7 | 3-pin 2.54mm | Mode toggle A/B/C (PB0/PB1/GND) | Molex KK or equiv | 1
J10 | 4-pin 2.54mm | SWD (SWDIO/SWDCLK/GND/3V3) | header | 1
J11 | 3-pin 2.54mm | UART (TX/RX/GND) 115200 8N1 | header | 1
J12 | 2-pin 2.54mm | BOOT0 button | header | 1
J13 | 2-pin 2.54mm | NRST button | header | 1
J14 | 4-pin 2.54mm | TM1637 display (CLK/DIO/GND/VCC) | header | 1
J_USB | USB-C 16-pin | USB-C receptacle (UART reflash + 5V) | HRO TYPE-C-31-M-12 | 1 | CC1/CC2 5.1k pulldowns.
GD3 | Op-amp (RRIO HV) | Anti-brake demand translator: unity difference referenced to WHITE (AB_DEMAND=WHITE-0.30V) | SOT-23 (LM7321) or pairs with GD1 in one LM7322 dual | 1 | Exact + WHITE-independent. Replaces the 2N2222 level-shift.
R_t1-R_t4 | 10k 0.1% | Anti-brake translator difference resistors (matched set of 4) | 0402 | 4 | Matching sets WHITE-rail rejection; all four equal -> AB_DEMAND=WHITE-Vdivider.
R_SAFE | 100k | C3 safe-default pull-up: Q2 drain (BLACK_to_track) to gate | 0402 | 1 | Passive back-EMF gate drive on power loss. ~0.16mA at 16V; GD2 sinks it when powered.
D_SAFE | MMSZ5242B (12V Zener) | C3 gate clamp: Q2 gate to source (RED) | SOD-123 | 1 | Clamps Vgs vs back-EMF + spikes. NOTE value: 12V was per old IRFP250N; for logic-level Q2 ~8.2V fully enhances with more gate-oxide margin - confirm vs FET Vgs(max).

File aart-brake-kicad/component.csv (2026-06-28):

U1 STM32G051K6U6  C5270224  "ARM Cortex-M0+ UFQFPN-32(5x5) Microcontrollers (MCU/MPU/SOC) ROHS"
U2 AMS1117-3.3  C6186 C347222 "-40?~+125? 0.003%Vout 1 1.1V@(800mA) 15V 1A 3.3V 5mA 72dB@(120Hz) Fixed Over Current Protection?Short Circuit Protection?Thermal shutdown Positive SOT-223 Voltage Regulators - Linear, Low Drop Out (LDO) Regulators ROHS"
U3 CH340N  C2977777  "-20?~+70? 1 2Mbps 3.3V?5V USB 2.0 USB to serial SOP-8 USB Converters ROHS"        SOP-8    USB-UART bridge
U4 MCP1700-5002  C631989  "-40?~+125?@(Tj) 1 1.6uA 250mA 350mV@(250mA) 44dB@(1kHz) 5V 6V Fixed Over Temperature Protection?Short Circuit Protection Positive TO-92-3 Voltage Regulators - Linear, Low Drop Out (LDO) Regulators ROHS"          (GD2 brake buffer only; GD1 on WHITE)
U5 TPS12120QRGERQ1 TPS1212-Q1 C48907823  "Automotive 74V low-Iq high-side driver with bidirectional current monitoring, I2t and diagnostics | RGE | 23 | -40 to 125" https://www.ti.com/product/TPS1212-Q1/part-details/TPS12120QRGERQ1   VQFN-23  Smart high-side switch controller for Q5/Q6 (VS from WHITE):
GD2 MCP6006T-E/OT TLV9001IDBVR C4369359 C398363 "-40?~+125? 1 1.6mV 1.8V~5.5V 119pA 1MHz 1pA 25nV/?Hz@1kHz 30mA 3V/us 600nV/? 6V 70uA 90dB Rail-to-Rail Input, Rail-to-Rail Output SOT-23-5 Operational Amplifier ROHS"       -> Q2, linear)
GD1 MCP6006T-E/OT  C4369359  "-40?~+125? 1 1.6mV 1.8V~5.5V 119pA 1MHz 1pA 25nV/?Hz@1kHz 30mA 3V/us 600nV/? 6V 70uA 90dB Rail-to-Rail Input, Rail-to-Rail Output SOT-23-5 Operational Amplifier ROHS"    SOT-23-5  Anti-brake CURRENT-SOURCE loop on WHITE rail (PWM demand -> Q1; Rsense 0.1ohm)
Q1 TIP147  C84047  "1000 100V 10A 125W 1mA 3V 3V 5V PNP TO-247 Darlington Transistors ROHS"    TO-220  PNP Darlington anti-brake current-source pass (100V 10A 125W) + HEATSINK
Q2 IRFP250N IRFP250NPBF C20624228 C2580 "-55?~+150? 1 N-channel 101pF 104W 2.8nF 200V 30A 355pF 4V 80m?@10V N-Channel TO-247 MOSFETs ROHS"  TO-247  Wide-SOA N-ch brake FET (30A 200V) + HEATSINK
       SUP70060E / RFP50N06 / FDP61N20)
Rsense 0.1ohm WSR3R1000FEA 1-2W C511044 "-65?~+275? 100m? 3W ±1% ±75ppm/? 4527 Chip Resistor - Surface Mount ROHS" anti-brake current sense (0.3V at 3A)
Q_LS 2N2222  C118536  "1 NPN 10nA 1V 250MHz 40 40V 600mA 625mW 6V NPN TO-92 Bipolar (BJT) ROHS" level-shift   C_KA 470n + R 10k/1k  PWM->DC demand filter
Q5 STL059N4S8AG BSC059N04LSG  C151526 PowerFLAT  Reverse-block N-ch (40V 0.59mohm)
Q6 STL059N4S8AG BSC059N04LSG  C151526 PowerFLAT  Reverse-block N-ch (common-source with Q5)
     (alt Q5/Q6: Vishay SiJK140E 0.34mohm)
Diodes
D1 P6KE18CA  C8926  "-55?~+150? 15.3V 18.9V 1uA 24A@10/1000us 25.2V 600W@10/1000us TVS DO-15 ESD and Surge Protection (TVS/ESD) ROHS" SMB  TVS bidirectional (WHITE rail clamp; CA essential)
D2 SS310B SS310 C14281 C15874 "-55?~+125? 100V 3A 500uA@100V 850mV@3A Independent SMA(DO-214AC) Schottky Diodes ROHS"    SMB  Q2 catch diode (100V)
D4 MBRS360T3G MBRS360BT3G C24449 C59027 "-65?~+175? 1 Independent 125A 30uA@60V 3A 60V 630mV@3A SMB(DO-214AA) Schottky Diodes ROHS"  SMB  Anti-brake follower reverse block (emitter -> track)
RSNS ~0.5-0.75mohm    TPS1212 main-path current sense (CS1+/CS1-)
CI2t/CTMR/RIOC   TPS1212  I2t breaker time, retry timer, OCP threshold
D5   LED  Red   805  Status LED (PB6)
Passives
F1   500mA-1A  polyfuse 1812  WHITE rail MCU/analog supply ONLY (never BLACK)
R2   10k  402  GD2 input safe-default pull-up
R3   10R  402  Q2 gate    R_BASE 1k 402  Q1 Darlington base
Rsense 0.1ohm    anti-brake current sense   RSNS ~0.5-0.75mohm  TPS1212 main-path sense
Q_LS 2N2222    PWM level-shift   C_KA 470n + R 10k/1k  PWM->DC filter
R8   15k  / R9 4k7  WHITE sense divider (PA0)
R10 22k  /  R11 4k7 BLACK sense divider (PA1, track side of switch)
R5   10k   Pot ref to 3.3V    R12 330R  Status LED
C1-C7 decoupling  (LDO  rails + MCU VDD/VDDA)
Connectors
J1-J6   4mm  banana  Track + controller WHITE/BLACK/RED (x2 sides)
J7   3-pin  2.54mm  Mode toggle A/B/C (PB0/PB1/GND)
J10 4-pin  SWD   J11 3-pin UART  J12 BOOT0  J13 NRST
J14 3-pin  voltmeter
NOTE: J9  capture  button REMOVED (toggle replaces it; PB3 reserved/optional)

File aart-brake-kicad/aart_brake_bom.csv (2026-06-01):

Reference | Value | Description | Package | Quantity | Notes
U1 | STM32G041K6U6 | ARM Cortex-M0+ MCU 32K flash 8K RAM | QFN-32 5x5mm | 1 | Main controller
U2 | AMS1117-3.3 | LDO regulator 12V to 3.3V 1A | SOT-223 | 1
GD1 | UCC27524 | Dual 4A gate driver — brake channel | SOT-23-5 | 1 | Both outputs paralleled for Q1
GD2 | UCC27524 | Dual 4A gate driver — keep-alive channel | SOT-23-5 | 1 | Both outputs paralleled for Q2
Q1 | IRLB3034 | N-ch MOSFET 40V 195A 1.4mohm — brake FET | D2PAK (TO-263) | 1 | Low-side across motor terminals
Q2 | IRF9Z34N | P-ch MOSFET 55V 18A — keep-alive FET | D2PAK (TO-263) | 1 | High-side from 12V rail to track+
D1 | P6KE18CA | TVS diode 18V BIDIRECTIONAL (CA suffix) | SMB (DO-214AA) | 1 | Rail transient clamp for 16V rail. CA suffix = bidirectional — essential for inductive switching transients both polarities
D2 | SS310 | Schottky 3A 100V — Q1 catch diode | SMB (DO-214AA) | 1 | 100V reverse rating required — inductive turn-off spike on 16V rail. SS34 (40V) has insufficient margin
D3 | SS310 | Schottky 3A 100V — Q2 catch diode | SMB (DO-214AA) | 1 | Same upgrade as D2
D4 | MBRS360 or SS54 | Schottky 3A 60V (MBRS360) or 5A 40V (SS54) — mode C series protection | SMB (DO-214AA) | 1 | ESSENTIAL for mode C. Sees repetitive ~46A pulses at 20kHz during hard braking. SS34 marginal under repetitive stress. MBRS360 same footprint.
D5 | LED Red | Status indicator — flash save confirmation | 0805 | 1
F1 | Polyfuse 25A | Resettable fuse — rail protection | 1812 | 1 | e.g. Bourns MF-R250
C1 | 10µF 25V | LDO input bulk decoupling | 0805 | 1
C2 | 100nF 25V | LDO input HF decoupling | 0402 | 1
C3 | 10µF 10V | LDO output bulk decoupling | 0805 | 1
C4 | 100nF 10V | LDO output HF decoupling | 0402 | 1
C5 | 100nF 10V | MCU VDD decoupling | 0402 | 1 | Place as close to VDD pin as possible
C6 | 100nF 10V | MCU VDDA decoupling | 0402 | 1 | Place as close to VDDA pin as possible
C7 | 4.7µF 10V | MCU VDDA bulk | 0402 | 1
R1 | 10k | NRST pull-up | 0402 | 1
R2 | 10k | GD1 input pull-up — safe default brake | 0402 | 1 | Placed BEFORE GD1 input — not on Q1 gate
R3 | 10R | Q1 gate resistor | 0402 | 1 | Slows switching to reduce EMI
R4 | 10R | Q2 gate resistor | 0402 | 1
R5 | 10k | Pot top-end to 3.3V | 0402 | 1 | Sets pot voltage reference
R6 | 10k | Capture button pull-up PA5 to 3.3V | 0402 | 1
R7 | 1k | Capture button series to GND | 0402 | 1 | With R6 gives 0.3V pressed / 3.3V unpressed
R8 | 15k | Rail sense top divider PA0 | 0402 | 1 | V_PA0 = 12.4 x 4.7/(15+4.7) = 2.96V
R9 | 4k7 | Rail sense bottom divider PA0 | 0402 | 1
R10 | 330R | Status LED current limit | 0402 | 1 | (3.3V - 2.0V) / 330 = ~4mA
J1 | 2-pin 5mm | Track output +/- | KF2EDGK-5.0 or equiv | 1 | High-current terminal block
J2 | 2-pin 5mm | 12.4V rail input (always live) | KF2EDGK-5.0 or equiv | 1 | High-current terminal block
J3 | 2-pin 5mm | Hand controller input | KF2EDGK-5.0 or equiv | 1 | High-current terminal block
J4 | 3-pin 2.54mm | Pot connector (3.3V / wiper / GND) | Molex KK or equiv | 1 | Centre-detent 10k pot
J5 | 3-pin 2.54mm | Mode toggle (bit0 / bit1 / GND) | Molex KK or equiv | 1 | 3-position toggle switch
J6 | 2-pin 2.54mm | Capture button | Molex KK or equiv | 1 | Momentary pushbutton
J7 | 2-pin 2.54mm | Wiper strip input | Molex KK or equiv | 1 | From hand controller wiper contact

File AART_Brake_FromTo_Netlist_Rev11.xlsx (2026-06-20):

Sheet: Nets
Net | Class | Connected pins (Ref.PinName — function) | Notes
+12V_RAIL | PWR (WHITE, raw/unfused, high-current) | J1.1 — WHITE track jack J2.1 — WHITE ctrl jack (pass-through) D1.1 — P6KE18CA TVS (other end GND) F1.1 — polyfuse in U5.VS — TPS1212 supply from WHITE (3.5-73V, no clamp) Rsns_ab.1 — anti-brake sense top (0.1ohm) R_KA1.1 — demand-filter pull-up to WHITE C_KA.1 — demand-filter cap to WHITE GD1.V+ — anti-brake op-amp supply <-- POWERED FROM WHITE, see notes R8.1 — WHITE sense divider top | WHITE rail. Anti-brake current source draws up to 3A here; must NOT go through F1.
VWHITE_FUSED | PWR (WHITE after F1 -> LDOs) | F1.2 — polyfuse out U2.IN — AMS1117-3.3 in U4.IN — MCP1700-5002 in C1.1 — LDO input bulk + C2.1 — LDO input HF + D_USB.K — BAT54 cathode (USB 5V OR-in) | Low-current LDO supply. USB VBUS OR's in here via D_USB for reflash-on-USB.
+3V3 | PWR (MCU rail) | U2.OUT — AMS1117 out C3.1 — out bulk + C4.1 — out HF + U1.VDD — MCU digital supply U1.VDDA — MCU analog supply C5.1 — VDD decoupling C6.1 — VDDA decoupling C7.1 — VDDA bulk R1.1 — NRST pull-up top Pot.1 — pot top (via R5 if fitted) R5.1 — pot top reference U3.VCC — CH340N supply (3.3V logic) J10.1 — SWD 3V3 | 3.3V logic rail.
+5V | PWR (brake-buffer rail) | U4.OUT — MCP1700 out C4b.1 — 5V decoupling GD2.V+ — brake op-amp supply R2.1 — brake safe-default pull-up to 5V | 5V analog rail. NOTE: only GD2 (brake buffer) lives here now; GD1 moved to WHITE.
GND | PWR (common 0V / RED return) | J5.1 — RED track jack J6.1 — RED ctrl jack U1.VSS — MCU ground U1.VSSA — MCU analog ground U2.GND U4.GND GD1.V- — op-amp neg supply GD2.V- U5.GND — TPS1212 ground / thermal pad U3.GND Q2.S — IRFP250N source = RED low-side return D1.2 — TVS to GND D2.A — catch-diode anode Rsns_ab.- — (no) Q_LS.E — 2N2222 emitter (via R_KAe) R9.2 — WHITE divider bottom R11.2 — BLACK divider bottom Pot.3 — pot bottom C1.2 — |C2.2|C3.2|C4.2|C4b.2|C5.2|C6.2|C7.2|C_KA? (C_KA is to WHITE) CI2t.2 — TPS1212 I2t cap CTMR.2 — TPS1212 timer cap RIOC.2 — OCP set R12.- — (LED cathode side via D5.K) D5.K — status LED cathode J7.3 — toggle common J10.2 — SWD GND J11.3 — UART GND J12.2 — BOOT0 btn return J13.2 — NRST btn return J14.2 — voltmeter GND | Star/plane ground. Keep the 40A BLACK/brake return (RED) copper separate from signal GND, joined at one point.
RAIL_SENSE | ANALOG (WHITE divider -> ADC) | U1.PA0 — ADC_IN0 R8.2 — divider tap R9.1 — divider tap | R8=15k(top to +12V_RAIL), R9=4k7(bottom to GND). 16V -> <3.3V.
BLACK_SENSE | ANALOG (BLACK divider -> ADC) | U1.PA1 — ADC_IN1 R10.2 — divider tap R11.1 — divider tap | R10=22k(top to TRACK_POS), R11=4k7(bottom to GND). Tap on TRACK side of switch.
POT_WIPER | ANALOG (pot -> ADC) | U1.PA3 — ADC_IN3 Pot.2 — wiper | Single control pot. CCW=min, CW=max.
BRAKE_DAC | ANALOG (DAC1 -> brake buffer) | U1.PA4 — DAC_CH1 out GD2.IN+ — non-inverting R2.2 — safe-default pull-up (R2.1->+5V) | On MCU reset DAC is Hi-Z; R2 pulls GD2 input to +5V -> Q2 defaults to braking (fail-safe).
BRAKE_GATE_DRV | ANALOG (buffer out) | GD2.OUT GD2.IN- — unity feedback R3.1 — gate resistor | GD2 = unity buffer; may need gain >1 to reach ~5V gate from 3.3V DAC for IRFP250N - confirm.
Q2_GATE | ANALOG | R3.2 — 10R gate Q2.G — IRFP250N gate
TRACK_POS | PWR-BLACK (track + / motor + / injection) | J3.1 — BLACK track jack Q6.D — reverse-switch track-side drain Q2.D — brake FET drain (shunts to GND to brake) D2.K — catch-diode cathode D4.K — anti-brake injection diode cathode R10.1 — BLACK sense divider top | The shared BLACK-to-track node: switch output, brake high side, anti-brake injection, sense tap.
CTRL_BLACK_IN | PWR-BLACK (controller in) | J4.1 — BLACK ctrl jack Rsns_sw.1 — TPS1212 sense in U5.CS1+ — sense + | Controller BLACK in. Separate net from TRACK_POS (switch is between them).
SW_FET_IN | PWR-BLACK (after sense R) | Rsns_sw.2 — sense out Q5.D — ctrl-side drain U5.CS1- — sense - | Rsns_sw ~0.5-0.75mohm. CS1+/CS1- straddle it (Kelvin).
SW_COMMON_SRC | PWR-BLACK (Q5/Q6 common source) | Q5.S Q6.S U5.SRC — TPS1212 source ref / charge-pump return | Common source = TPS1212 SRC. Bootstrap cap C_BST sits BST->SRC.
SW_GATE | ANALOG (common gate) | Q5.G Q6.G U5.GATE — charge-pumped gate drive | TPS1212 GATE drives both gates (2A sink for fast turn-off).
U5_BST | ANALOG (bootstrap) | U5.BST C_BST.1 — bootstrap cap (C_BST.2 -> SRC) | 100nF typ.
U5_IDIR | DIGITAL (reverse flag) | U5.I_DIR — open-drain, low on reverse Q_GL.in — glue input | I_DIR -> glue -> INP. CONFIRM polarity & glue topology vs TPS1212 reference.
U5_INP | DIGITAL (on/off command) | U5.INP — gate command Q_GL.out — glue pulls INP low on reverse | Normally enabled; glue forces off on reverse. Fast turn-off path.
U5_CI2t | ANALOG | U5.CI2t CI2t.1 — I2t breaker timer cap | sets OC fault time
U5_CTMR | ANALOG | U5.CTMR CTMR.1 — retry/latch timer cap
U5_IOC | ANALOG | U5.IOC RIOC.1 — OCP threshold set | trip ~50-60A
PB3_SW_EN | DIGITAL (optional enable) | U1.PB3 — reserved GPIO U5.EN — enable/UVLO (optional) | Optional MCU supervisory enable; default enabled. Unused in Rev 11 fw.
AB_SENSE | ANALOG-HV (current sense, ~WHITE) | Rsns_ab.2 — 0.1ohm sense bottom Q1.E — TIP147 emitter GD1.IN- — inverting (senses I) | I = (V_WHITE - V_AB_SENSE)/0.1ohm. Common mode ~16V -> GD1 must be a HV op-amp on WHITE.
AB_DEMAND | ANALOG-HV (current setpoint, ref to WHITE) | GD1.IN+ — non-inverting (demand) R_KA1.2 — filter pull-up from WHITE C_KA.2 — filter cap from WHITE Q_LS.C — level-shift collector | Per sim: demand node pulled to WHITE by R_KA1/C_KA, pulled down by Q_LS(PWM). Sets how far below WHITE -> sets current.
AB_BASE_DRV | ANALOG-HV (op-amp -> pass base) | GD1.OUT Q1.B — TIP147 base | GD1 output swings near WHITE; HV op-amp required.
AB_INJECT | PWR (pass collector -> diode) | Q1.C — TIP147 collector D4.A — MBRS360 anode | Injection current up to 3A; D4.K -> TRACK_POS.
KA_PWM | DIGITAL (MCU demand) | U1.PA5 — TIM2_CH1 PWM 50kHz R_KAbase.1 — level-shift base R | Filtered to DC by the level-shift+RC. R_KAbase.2 -> Q_LS.B.
KA_LS_BASE | ANALOG | R_KAbase.2 Q_LS.B — 2N2222 base
KA_LS_EMIT | ANALOG | Q_LS.E — via emitter R R_KAe.1 — emitter R (R_KAe.2->GND) | Emitter degeneration (R1 in sim).
UART_TX | DIGITAL | U1.PA9 — USART1_TX U3.RXD — CH340N receive J11.1 — UART header TX
UART_RX | DIGITAL | U1.PA10 — USART1_RX U3.TXD — CH340N transmit J11.2 — UART header RX
USB_DP | USB | U3.UD+ — CH340N D+ J_USB.DP — USB-C D+ (both CC pairs)
USB_DM | USB | U3.UD- — CH340N D- J_USB.DM — USB-C D-
VBUS | PWR (USB 5V) | J_USB.VBUS F_USB.1 — USB polyfuse C_USB.1 — VBUS bulk | F_USB.2 -> D_USB.A -> VWHITE_FUSED.
USB_CC1 | USB | J_USB.CC1 R_CC1.1 — 5.1k to GND
USB_CC2 | USB | J_USB.CC2 R_CC2.1 — 5.1k to GND
U3_V3 | ANALOG | U3.V3 — CH340N reg pin C_V3.1 — 100nF to GND | CH340N internal reg decoupling.
SWDIO | DIGITAL | U1.PA13 — SWDIO J10.3
SWDCLK | DIGITAL | U1.PA14 — SWDCLK J10.4
NRST | DIGITAL | U1.NRST R1.2 — pull-up bottom J13.1 — NRST button
BOOT0 | DIGITAL | U1.BOOT0 J12.1 — BOOT0 button (+pulldown R_B0)
TOGGLE_0 | DIGITAL | U1.PB0 — mode bit0 (int pull-up) J7.1 — toggle pos A
TOGGLE_1 | DIGITAL | U1.PB1 — mode bit1 (int pull-up) J7.2 — toggle pos B
VOLTMETER_PWM | ANALOG (PWM->DC meter) | U1.PB4 — TIM3_CH1 PWM R_v.1 — RC filter | R_v+C_v -> D_v -> J14.1.
VM_OUT | ANALOG | R_v.2 C_v.1 — filter cap to GND D_v.A — series diode
VM_JACK | ANALOG | D_v.K J14.1 — voltmeter +
LED_DRV | DIGITAL | U1.PB6 — status LED GPIO R12.1 — LED series R
LED_A |  | R12.2 D5.A — status LED anode | D5.K -> GND.

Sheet: Component Pinout
Ref | Part | Pin | Net | Function / notes
C1 | LDO in bulk | 1 | VWHITE_FUSED | LDO input bulk +
C1 | LDO in bulk | 2 | GND | |C2.2|C3.2|C4.2|C4b.2|C5.2|C6.2|C7.2|C_KA? (C_KA is to WHITE)
C2 | LDO in HF | 1 | VWHITE_FUSED | LDO input HF +
C3 | 3V3 out bulk | 1 | +3V3 | out bulk +
C4 | 3V3 out HF | 1 | +3V3 | out HF +
C4b | 5V decoupling | 1 | +5V | 5V decoupling
C5 | VDD decap | 1 | +3V3 | VDD decoupling
C6 | VDDA decap | 1 | +3V3 | VDDA decoupling
C7 | VDDA bulk | 1 | +3V3 | VDDA bulk
CI2t | I2t timer | 2 | GND | TPS1212 I2t cap
CI2t | I2t timer | 1 | U5_CI2t | I2t breaker timer cap
CTMR | retry timer | 2 | GND | TPS1212 timer cap
CTMR | retry timer | 1 | U5_CTMR | retry/latch timer cap
C_BST | TPS1212 bootstrap | 1 | U5_BST | bootstrap cap (C_BST.2 -> SRC)
C_KA | 470n demand filter | 1 | +12V_RAIL | demand-filter cap to WHITE
C_KA | 470n demand filter | 2 | AB_DEMAND | filter cap from WHITE
C_USB | VBUS bulk | 1 | VBUS | VBUS bulk
C_V3 | CH340N V3 decap | 1 | U3_V3 | 100nF to GND
C_v | voltmeter filter | 1 | VM_OUT | filter cap to GND
D1 | P6KE18CA TVS | 1 | +12V_RAIL | P6KE18CA TVS (other end GND)
D1 | P6KE18CA TVS | 2 | GND | TVS to GND
D2 | SS310 catch | A | GND | catch-diode anode
D2 | SS310 catch | K | TRACK_POS | catch-diode cathode
D4 | MBRS360 inject block | K | TRACK_POS | anti-brake injection diode cathode
D4 | MBRS360 inject block | A | AB_INJECT | MBRS360 anode
D5 | status LED | K | GND | status LED cathode
D5 | status LED | A | LED_A | status LED anode
D_USB | BAT54 USB-OR | K | VWHITE_FUSED | BAT54 cathode (USB 5V OR-in)
D_v | voltmeter series | A | VM_OUT | series diode
D_v | voltmeter series | K | VM_JACK
F1 | polyfuse WHITE | 1 | +12V_RAIL | polyfuse in
F1 | polyfuse WHITE | 2 | VWHITE_FUSED | polyfuse out
F_USB | USB polyfuse | 1 | VBUS | USB polyfuse
GD1 | Op-amp (HV, on WHITE) anti-brake loop | V+ | +12V_RAIL | anti-brake op-amp supply <-- POWERED FROM WHITE, see notes
GD1 | Op-amp (HV, on WHITE) anti-brake loop | V- | GND | op-amp neg supply
GD1 | Op-amp (HV, on WHITE) anti-brake loop | IN- | AB_SENSE | inverting (senses I)
GD1 | Op-amp (HV, on WHITE) anti-brake loop | IN+ | AB_DEMAND | non-inverting (demand)
GD1 | Op-amp (HV, on WHITE) anti-brake loop | OUT | AB_BASE_DRV
GD2 | Op-amp (5V) brake buffer | V+ | +5V | brake op-amp supply
GD2 | Op-amp (5V) brake buffer | V- | GND
GD2 | Op-amp (5V) brake buffer | IN+ | BRAKE_DAC | non-inverting
GD2 | Op-amp (5V) brake buffer | OUT | BRAKE_GATE_DRV
GD2 | Op-amp (5V) brake buffer | IN- | BRAKE_GATE_DRV | unity feedback
J1 | WHITE track banana | 1 | +12V_RAIL | WHITE track jack
J10 | SWD 4-pin | 1 | +3V3 | SWD 3V3
J10 | SWD 4-pin | 2 | GND | SWD GND
J10 | SWD 4-pin | 3 | SWDIO
J10 | SWD 4-pin | 4 | SWDCLK
J11 | UART 3-pin | 3 | GND | UART GND
J11 | UART 3-pin | 1 | UART_TX | UART header TX
J11 | UART 3-pin | 2 | UART_RX | UART header RX
J12 | BOOT0 btn | 2 | GND | BOOT0 btn return
J12 | BOOT0 btn | 1 | BOOT0 | BOOT0 button (+pulldown R_B0)
J13 | NRST btn | 2 | GND | NRST btn return
J13 | NRST btn | 1 | NRST | NRST button
J14 | voltmeter 3-pin | 2 | GND | voltmeter GND
J14 | voltmeter 3-pin | 1 | VM_JACK | voltmeter +
J2 | WHITE ctrl banana | 1 | +12V_RAIL | WHITE ctrl jack (pass-through)
J3 | BLACK track banana | 1 | TRACK_POS | BLACK track jack
J4 | BLACK ctrl banana | 1 | CTRL_BLACK_IN | BLACK ctrl jack
J5 | RED track banana | 1 | GND | RED track jack
J6 | RED ctrl banana | 1 | GND | RED ctrl jack
J7 | mode toggle 3-pin | 3 | GND | toggle common
J7 | mode toggle 3-pin | 1 | TOGGLE_0 | toggle pos A
J7 | mode toggle 3-pin | 2 | TOGGLE_1 | toggle pos B
J_USB | USB-C recept | DP | USB_DP | USB-C D+ (both CC pairs)
J_USB | USB-C recept | DM | USB_DM | USB-C D-
J_USB | USB-C recept | VBUS | VBUS
J_USB | USB-C recept | CC1 | USB_CC1
J_USB | USB-C recept | CC2 | USB_CC2
Pot | 10k linear control pot | 1 | +3V3 | pot top (via R5 if fitted)
Pot | 10k linear control pot | 3 | GND | pot bottom
Pot | 10k linear control pot | 2 | POT_WIPER | wiper
Q1 | TIP147 PNP Darlington (or N-MOSFET) anti-brake pass | E | AB_SENSE | TIP147 emitter
Q1 | TIP147 PNP Darlington (or N-MOSFET) anti-brake pass | B | AB_BASE_DRV | TIP147 base
Q1 | TIP147 PNP Darlington (or N-MOSFET) anti-brake pass | C | AB_INJECT | TIP147 collector
Q2 | IRFP250N brake FET | S | GND | IRFP250N source = RED low-side return
Q2 | IRFP250N brake FET | G | Q2_GATE | IRFP250N gate
Q2 | IRFP250N brake FET | D | TRACK_POS | brake FET drain (shunts to GND to brake)
Q5 | STL059N4S8AG N-ch reverse | D | SW_FET_IN | ctrl-side drain
Q5 | STL059N4S8AG N-ch reverse | S | SW_COMMON_SRC
Q5 | STL059N4S8AG N-ch reverse | G | SW_GATE
Q6 | STL059N4S8AG N-ch reverse | D | TRACK_POS | reverse-switch track-side drain
Q6 | STL059N4S8AG N-ch reverse | S | SW_COMMON_SRC
Q6 | STL059N4S8AG N-ch reverse | G | SW_GATE
Q_GL | glue transistor (I_DIR->INP) | in | U5_IDIR | glue input
Q_GL | glue transistor (I_DIR->INP) | out | U5_INP | glue pulls INP low on reverse
Q_LS | 2N2222 PWM level-shift | E | GND | 2N2222 emitter (via R_KAe)
Q_LS | 2N2222 PWM level-shift | C | AB_DEMAND | level-shift collector
Q_LS | 2N2222 PWM level-shift | B | KA_LS_BASE | 2N2222 base
Q_LS | 2N2222 PWM level-shift | E | KA_LS_EMIT | via emitter R
R1 | NRST pull-up 10k | 1 | +3V3 | NRST pull-up top
R1 | NRST pull-up 10k | 2 | NRST | pull-up bottom
R10 | 22k BLACK sense | 2 | BLACK_SENSE | divider tap
R10 | 22k BLACK sense | 1 | TRACK_POS | BLACK sense divider top
R11 | 4k7 BLACK sense | 2 | GND | BLACK divider bottom
R11 | 4k7 BLACK sense | 1 | BLACK_SENSE | divider tap
R12 | LED series 330R | 1 | LED_DRV | LED series R
R12 | LED series 330R | 2 | LED_A
R2 | brake safe-default pull-up 10k | 1 | +5V | brake safe-default pull-up to 5V
R2 | brake safe-default pull-up 10k | 2 | BRAKE_DAC | safe-default pull-up (R2.1->+5V)
R3 | Q2 gate 10R | 1 | BRAKE_GATE_DRV | gate resistor
R3 | Q2 gate 10R | 2 | Q2_GATE | 10R gate
R5 | pot top ref 10k | 1 | +3V3 | pot top reference
R8 | 15k WHITE sense | 1 | +12V_RAIL | WHITE sense divider top
R8 | 15k WHITE sense | 2 | RAIL_SENSE | divider tap
R9 | 4k7 WHITE sense | 2 | GND | WHITE divider bottom
R9 | 4k7 WHITE sense | 1 | RAIL_SENSE | divider tap
RIOC | OCP set R | 2 | GND | OCP set
RIOC | OCP set R | 1 | U5_IOC | OCP threshold set
R_CC1 | USB CC 5.1k | 1 | USB_CC1 | 5.1k to GND
R_CC2 | USB CC 5.1k | 1 | USB_CC2 | 5.1k to GND
R_KA1 | demand filter pull-up | 1 | +12V_RAIL | demand-filter pull-up to WHITE
R_KA1 | demand filter pull-up | 2 | AB_DEMAND | filter pull-up from WHITE
R_KAbase | level-shift base R | 1 | KA_PWM | level-shift base R
R_KAbase | level-shift base R | 2 | KA_LS_BASE
R_KAe | level-shift emitter R | 1 | KA_LS_EMIT | emitter R (R_KAe.2->GND)
R_v | voltmeter RC R | 1 | VOLTMETER_PWM | RC filter
R_v | voltmeter RC R | 2 | VM_OUT
Rsns_ab | 0.1ohm anti-brake current sense | 1 | +12V_RAIL | anti-brake sense top (0.1ohm)
Rsns_ab | 0.1ohm anti-brake current sense | 2 | AB_SENSE | 0.1ohm sense bottom
Rsns_sw | ~0.5-0.75mohm TPS1212 sense | 1 | CTRL_BLACK_IN | TPS1212 sense in
Rsns_sw | ~0.5-0.75mohm TPS1212 sense | 2 | SW_FET_IN | sense out
U1 | STM32G051K6U6 (QFN-32) MCU | VDD | +3V3 | MCU digital supply
U1 | STM32G051K6U6 (QFN-32) MCU | VDDA | +3V3 | MCU analog supply
U1 | STM32G051K6U6 (QFN-32) MCU | VSS | GND | MCU ground
U1 | STM32G051K6U6 (QFN-32) MCU | VSSA | GND | MCU analog ground
U1 | STM32G051K6U6 (QFN-32) MCU | PA0 | RAIL_SENSE | ADC_IN0
U1 | STM32G051K6U6 (QFN-32) MCU | PA1 | BLACK_SENSE | ADC_IN1
U1 | STM32G051K6U6 (QFN-32) MCU | PA3 | POT_WIPER | ADC_IN3
U1 | STM32G051K6U6 (QFN-32) MCU | PA4 | BRAKE_DAC | DAC_CH1 out
U1 | STM32G051K6U6 (QFN-32) MCU | PB3 | PB3_SW_EN | reserved GPIO
U1 | STM32G051K6U6 (QFN-32) MCU | PA5 | KA_PWM | TIM2_CH1 PWM 50kHz
U1 | STM32G051K6U6 (QFN-32) MCU | PA9 | UART_TX | USART1_TX
U1 | STM32G051K6U6 (QFN-32) MCU | PA10 | UART_RX | USART1_RX
U1 | STM32G051K6U6 (QFN-32) MCU | PA13 | SWDIO | SWDIO
U1 | STM32G051K6U6 (QFN-32) MCU | PA14 | SWDCLK | SWDCLK
U1 | STM32G051K6U6 (QFN-32) MCU | NRST | NRST
U1 | STM32G051K6U6 (QFN-32) MCU | BOOT0 | BOOT0
U1 | STM32G051K6U6 (QFN-32) MCU | PB0 | TOGGLE_0 | mode bit0 (int pull-up)
U1 | STM32G051K6U6 (QFN-32) MCU | PB1 | TOGGLE_1 | mode bit1 (int pull-up)
U1 | STM32G051K6U6 (QFN-32) MCU | PB4 | VOLTMETER_PWM | TIM3_CH1 PWM
U1 | STM32G051K6U6 (QFN-32) MCU | PB6 | LED_DRV | status LED GPIO
U2 | AMS1117-3.3 LDO | IN | VWHITE_FUSED | AMS1117-3.3 in
U2 | AMS1117-3.3 LDO | OUT | +3V3 | AMS1117 out
U2 | AMS1117-3.3 LDO | GND | GND
U3 | CH340N USB-UART | VCC | +3V3 | CH340N supply (3.3V logic)
U3 | CH340N USB-UART | GND | GND
U3 | CH340N USB-UART | RXD | UART_TX | CH340N receive
U3 | CH340N USB-UART | TXD | UART_RX | CH340N transmit
U3 | CH340N USB-UART | UD+ | USB_DP | CH340N D+
U3 | CH340N USB-UART | UD- | USB_DM | CH340N D-
U3 | CH340N USB-UART | V3 | U3_V3 | CH340N reg pin
U4 | MCP1700-5002 LDO 5V | IN | VWHITE_FUSED | MCP1700-5002 in
U4 | MCP1700-5002 LDO 5V | OUT | +5V | MCP1700 out
U4 | MCP1700-5002 LDO 5V | GND | GND
U5 | TPS1212-Q1 (VQFN-23) hi-side ctrl | VS | +12V_RAIL | TPS1212 supply from WHITE (3.5-73V, no clamp)
U5 | TPS1212-Q1 (VQFN-23) hi-side ctrl | GND | GND | TPS1212 ground / thermal pad
U5 | TPS1212-Q1 (VQFN-23) hi-side ctrl | CS1+ | CTRL_BLACK_IN | sense +
U5 | TPS1212-Q1 (VQFN-23) hi-side ctrl | CS1- | SW_FET_IN | sense -
U5 | TPS1212-Q1 (VQFN-23) hi-side ctrl | SRC | SW_COMMON_SRC | TPS1212 source ref / charge-pump return
U5 | TPS1212-Q1 (VQFN-23) hi-side ctrl | GATE | SW_GATE | charge-pumped gate drive
U5 | TPS1212-Q1 (VQFN-23) hi-side ctrl | BST | U5_BST
U5 | TPS1212-Q1 (VQFN-23) hi-side ctrl | I_DIR | U5_IDIR | open-drain, low on reverse
U5 | TPS1212-Q1 (VQFN-23) hi-side ctrl | INP | U5_INP | gate command
U5 | TPS1212-Q1 (VQFN-23) hi-side ctrl | CI2t | U5_CI2t
U5 | TPS1212-Q1 (VQFN-23) hi-side ctrl | CTMR | U5_CTMR
U5 | TPS1212-Q1 (VQFN-23) hi-side ctrl | IOC | U5_IOC
U5 | TPS1212-Q1 (VQFN-23) hi-side ctrl | EN | PB3_SW_EN | enable/UVLO (optional)

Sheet: Confirm & Notes
Topic | Detail
CRITICAL — design correction surfaced by the sim | GD1 (anti-brake op-amp) must be powered from the WHITE rail (~16V), NOT the +5V rail. In AntibrakeConstCurrent.wxsch the op-amp Vsup+ ties to V3 (WHITE) and it senses just below the rail (common mode ~16V). A 5V op-amp cannot do this. Use a single-supply HV op-amp (e.g. LM321/LM358-class, 3-32V) on WHITE. The current design doc/KiCad still say GD1 on +5V — needs fixing.
Anti-brake topology (per sim) | High-side current source referenced to WHITE: WHITE -> Rsns_ab(0.1ohm) -> Q1.E; GD1 holds Q1.E at the demand; I=(V_WHITE - V_demand)/0.1ohm. Demand node (AB_DEMAND) is pulled UP to WHITE by R_KA1/C_KA and pulled DOWN by the 2N2222 (Q_LS) driven by the MCU PWM. So PWM duty sets how far below WHITE the demand sits, i.e. the current. 3A max = 0.3V across Rsns_ab.
Pin NUMBERS need confirming | Pins here are by FUNCTION/NAME. Confirm exact pin numbers when you place symbols, especially U1 STM32G051K6U6 (QFN-32), U5 TPS1212-Q1 (VQFN-23), U3 CH340N. Wire by net name once symbols are placed and the numbers won't matter for connectivity.
Reverse switch sense (Rsns_sw) | TPS1212 senses across Rsns_sw via CS1+/CS1- (Kelvin). ~0.5-0.75mohm adds ~20-30mV at 40A. Set I2t/SCP/OCP (CI2t, CTMR, RIOC) for trip above 40A (~50-60A).
I_DIR -> INP glue | I_DIR is open-drain, low on reverse; it does NOT turn the FET off by itself. Q_GL/R_GL pull INP low on reverse for fast turn-off. CONFIRM polarity and exact glue against the TPS1212 reverse-protection reference before layout.
Brake buffer gain | GD2 shown as unity buffer. IRFP250N needs ~5V gate for low Rds; a 0-3.3V DAC buffered at gain 1 only reaches 3.3V. GD2 may need gain >1 (set by 2 resistors on IN-) to reach ~5V from +5V rail. Confirm against bench calibration / gen_brake_tables.py endpoints.
Fuse placement | F1 (500mA-1A) feeds ONLY the LDOs (VWHITE_FUSED). The anti-brake current source (up to 3A) and U5 VS tap raw +12V_RAIL ahead of F1. Never put the 40A BLACK path or the 3A injection through F1.
Ground separation | Keep the high-current RED return (Q2 source, brake/40A) copper separate from signal GND; join at a single star point. R9/R11 divider bottoms and ADC refs go to signal GND.
Voltmeter / USB sub-blocks | Voltmeter (PB4 PWM -> R_v/C_v -> D_v -> J14) and USB (J_USB/F_USB/D_USB/CC resistors/CH340N) are shown at standard-topology level; values per BOM. Confirm CH340N pinout and whether you power it at 3.3V or 5V.
What this table is | Net-centric 'from-to' wiring list for the AART braking module, Revision 11, reconstructed from the design doc + BOM + your SIMetrix sim. Use the Nets sheet to wire (connect all pins listed on each net); use Component Pinout to check nothing is left floating.

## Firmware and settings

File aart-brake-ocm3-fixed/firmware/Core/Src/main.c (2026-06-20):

/* ============================================================
 *  main.c — AART Slot Car Braking Module  Revision 11
 *  Target : STM32G051K6U6 (QFN-32)
 *  Library: libopencm3
 * ============================================================ */

#include "brake_module.h"
#include "uart_debug.h"

void sys_tick_handler(void)   { brake_systick_isr(); }
void hard_fault_handler(void) { brake_force_safe(); while (1) {} }
void nmi_handler(void)        { brake_force_safe(); while (1) {} }

int main(void)
{
    brake_init();
    uart_debug_init();

    while (1) {
        brake_tick();
        uart_debug_tick(brake_get_ctx());
    }
    return 0;
}

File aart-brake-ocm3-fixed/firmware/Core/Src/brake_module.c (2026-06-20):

/* ============================================================
 *  brake_module.c — AART Slot Car Braking Module  Revision 11
 *  Target  : STM32G051K6U6 (QFN-32)
 *  Library : libopencm3
 *
 *  Output stage: DAC1 (PA4) -> Q2 brake (linear).
 *  PWM (PA5, TIM2_CH1) -> filter -> Q1 anti-brake CURRENT SOURCE (3A).
 *  Both FETs operated in linear (triode) region — no PWM.
 *  D_PG (LTC4412) in BLACK controller input path.
 *  R10/R11 BLACK sense on motor side of D_PG.
 * ============================================================ */

#include "brake_module.h"
#include "uart_debug.h"

/* ── Private state ───────────────────────────────────────── */
static BrakeCtx_t        s_ctx;
static volatile uint32_t s_tick_ms   = 0;
static volatile bool     s_adc_ready = false;

/* DMA: [0]=WHITE(CH0) [1]=BLACK(CH1) [2]=pot(CH3) [3]=btn(CH8) */
static volatile uint16_t s_adc_buf[ADC_NUM_CHANNELS];

static uint32_t s_btn_last_ms = 0;
static bool     s_btn_prev    = false;
static uint32_t s_led_last_ms = 0;
static uint8_t  s_led_blinks  = 0;

/* ── SysTick ─────────────────────────────────────────────── */
void brake_systick_isr(void) { s_tick_ms++; }
static uint32_t now_ms(void) { return s_tick_ms; }

/* ── Linear map ──────────────────────────────────────────── */
static uint16_t map_u16(uint16_t v,
                         uint16_t il, uint16_t ih,
                         uint16_t ol, uint16_t oh)
{
    if (v <= il) return ol;
    if (v >= ih) return oh;
    return (uint16_t)(ol + ((uint32_t)(v-il)*(oh-ol))/(ih-il));
}

/* ── DAC setters ─────────────────────────────────────────── */
static void set_brake_dac(uint16_t val)
{
    if (val > 4095U) val = 4095U;
    dac_load_data_buffer_single(DAC1, val, DAC_ALIGN_RIGHT, DAC_BRAKE_CHAN);
    dac_software_trigger(DAC1, DAC_BRAKE_CHAN);
    s_ctx.brake_dac = val;
}

/* Anti-brake demand is now a 50kHz PWM duty, not a DAC code.   */
/* The PWM is filtered to DC and sets the current-source ref;   */
/* the current source bounds injection to ~3A regardless of      */
/* motor impedance (a stalled motor on the line is ~a short).    */
static void set_ka_pwm(uint16_t duty)
{
    if (duty > KA_PWM_ARR) duty = KA_PWM_ARR;
    timer_set_oc_value(KA_PWM_TIMER, KA_PWM_OC, duty);
    s_ctx.ka_dac = duty;          /* field reused: stores PWM duty */
}
/* compat shim for existing call sites */
static inline void set_ka_dac(uint16_t val) { set_ka_pwm(val); }

/* ── ADC raw → millivolts ────────────────────────────────── */
static uint16_t raw_to_mv(uint16_t raw, uint16_t num, uint16_t den)
{
    return (uint16_t)(((uint32_t)raw * 3300U * den)
                      / (4095U * num));
}

/* ── Keep-alive floor: should Q1 run? ───────────────────── */
/* Q1 only activates when V_BLACK_to_track would drop below
 * the saved keep-alive DAC floor. Suppressed when controller
 * is delivering power above the floor voltage.              */
static bool ka_should_run(uint16_t black_mv, uint16_t white_mv)
{
    /* Convert saved ka_dac to an approximate voltage on track.
     * Q1 P-ch: gate at DAC voltage, source at WHITE rail.
     * Simple approximation: floor_mv = (1 - dac/4095) * white_mv */
    uint32_t floor_mv = ((uint32_t)(4095U - s_ctx.saved_ka_dac)
                         * white_mv) / 4095U;
    return black_mv < (uint16_t)floor_mv;
}

/* ── LED ─────────────────────────────────────────────────── */
static void led_on(void)  { gpio_set(LED_PORT, LED_PIN); }
static void led_off(void) { gpio_clear(LED_PORT, LED_PIN); }

static void led_blink_start(void)
{
    s_led_blinks  = LED_BLINK_COUNT * 2U;
    s_led_last_ms = now_ms();
    led_on();
}

static void led_blink_tick(void)
{
    if (!s_led_blinks) return;
    if ((now_ms() - s_led_last_ms) < LED_BLINK_MS) return;
    s_led_last_ms = now_ms();
    if (--s_led_blinks & 1U) { led_on(); } else { led_off(); }
}

/* ── Clock (64MHz for UART accuracy; DAC unaffected by clock) */
static void clock_setup(void)
{
    const struct rcc_clock_scale cfg = {
        .sysclock_source  = RCC_PLL,
        .pll_source       = RCC_PLLCFGR_PLLSRC_HSI16,
        .pll_div          = RCC_PLLCFGR_PLLM_DIV(1),
        .pll_mul          = RCC_PLLCFGR_PLLN_MUL(8),
        .pllp_div         = RCC_PLLCFGR_PLLP_DIV(2),
        .pllq_div         = RCC_PLLCFGR_PLLQ_DIV(2),
        .pllr_div         = RCC_PLLCFGR_PLLR_DIV(2),
        .hpre             = RCC_CFGR_HPRE_NODIV,
        .ppre             = RCC_CFGR_PPRE_NODIV,
        .flash_waitstates = 2,
        .ahb_frequency    = 64000000,
        .apb_frequency    = 64000000,
        .voltage_scale    = PWR_SCALE1,
    };
    rcc_clock_setup(&cfg);
}

/* ── GPIO ────────────────────────────────────────────────── */
static void gpio_setup(void)
{
    rcc_periph_clock_enable(RCC_GPIOA);
    rcc_periph_clock_enable(RCC_GPIOB);

    /* PA0 WHITE sense, PA1 BLACK sense, PA3 pot — ADC analog   */
    gpio_mode_setup(GPIOA, GPIO_MODE_ANALOG, GPIO_PUPD_NONE,
                    GPIO0 | GPIO1 | GPIO3);

    /* PA4 DAC1 (Q2 brake) — analog                            */
    gpio_mode_setup(GPIOA, GPIO_MODE_ANALOG, GPIO_PUPD_NONE, GPIO4);
    /* PA5 = TIM2_CH1 (AF2) — anti-brake current demand PWM    */
    gpio_mode_setup(GPIOA, GPIO_MODE_AF, GPIO_PUPD_NONE, GPIO5);
    gpio_set_af(GPIOA, GPIO_AF2, GPIO5);

    /* PB0 toggle bit0, PB1 toggle bit1, PB3 capture btn        */
    gpio_mode_setup(GPIOB, GPIO_MODE_INPUT, GPIO_PUPD_PULLUP,
                    GPIO0 | GPIO1 | GPIO3);

    /* PB6 status LED                                            */
    gpio_mode_setup(LED_PORT, GPIO_MODE_OUTPUT, GPIO_PUPD_NONE, LED_PIN);
    led_off();
}

/* ── DAC setup ───────────────────────────────────────────── */
static void dac_setup(void)
{
    rcc_periph_clock_enable(RCC_DAC1);

    /* DAC1 CH1 only (brake). CH2 freed — anti-brake is PWM now. */
    dac_trigger_enable(DAC1, DAC_BRAKE_CHAN);
    dac_set_trigger_source(DAC1, DAC_CR_TSEL1_SW);  /* CH1 sw trigger */
    dac_enable(DAC1, DAC_BRAKE_CHAN);

    /* Safe default: Q2 brake off (0V). KA PWM set in ka_pwm_setup. */
    set_brake_dac(DAC_BRAKE_OFF);
}

/* ── Anti-brake demand PWM (TIM2_CH1, PA5 AF2) ──────────── */
/* 50kHz PWM, filtered to DC, sets the current-source demand.  */
/* Duty 0 = 0A (off); KA_PWM_ARR = ~3A. Bench-confirm the timer */
/* clock/prescaler so the period is 50kHz on the target board.  */
static void ka_pwm_setup(void)
{
    rcc_periph_clock_enable(RCC_TIM2);
    timer_set_mode(KA_PWM_TIMER, TIM_CR1_CKD_CK_INT,
                   TIM_CR1_CMS_EDGE, TIM_CR1_DIR_UP);
    timer_set_prescaler(KA_PWM_TIMER, 0U);
    timer_set_period(KA_PWM_TIMER, KA_PWM_ARR);   /* 50kHz */
    timer_set_oc_mode(KA_PWM_TIMER, KA_PWM_OC, TIM_OCM_PWM1);
    timer_set_oc_value(KA_PWM_TIMER, KA_PWM_OC, KA_PWM_OFF); /* off */
    timer_enable_oc_output(KA_PWM_TIMER, KA_PWM_OC);
    timer_enable_preload(KA_PWM_TIMER);
    timer_enable_counter(KA_PWM_TIMER);
    s_ctx.ka_dac = KA_PWM_OFF;
}
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

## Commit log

2026-06-01 Big update
    [aart_brake.kicad_sch, aart_brake_bom.csv]
2026-06-02 Debug pins
    [aart_brake.kicad_sch]
2026-06-03 Unwired KiCad
    [aart_brake.kicad_sch, brake_fet.kicad_sch, debug_headers.kicad_sch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]
2026-06-06 Latest doc
    [brake_fet.kicad_sch, keepalive_fet.kicad_sch, mcu_inputs.kicad_sch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]
2026-06-06 Add TODO section to README
    Added a TODO section with design verification and KiCad file generation tasks.
2026-06-11 All but KiCad
2026-06-12 Release candidate
    [aart_brake.kicad_sch, aart_brake_bom.csv, brake_fet.kicad_sch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]
2026-06-13 Added brake gen/test
2026-06-28 perfect diode modelling
    [component.csv]
